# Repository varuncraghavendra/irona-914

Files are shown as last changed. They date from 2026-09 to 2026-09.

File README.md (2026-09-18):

# Irona - The Flying Dexterous Humanoid

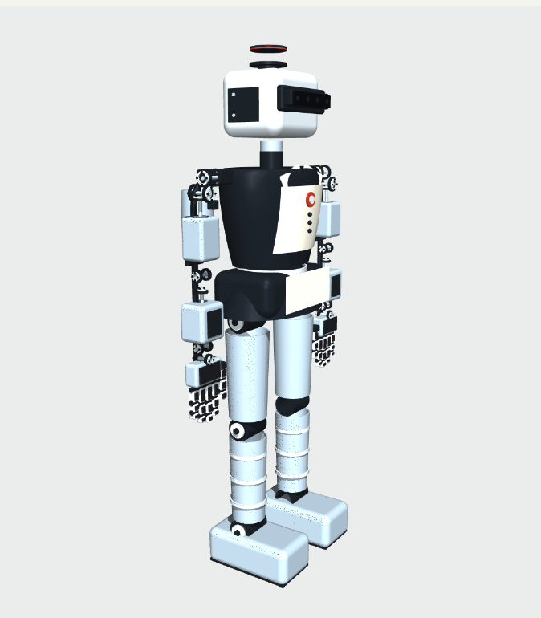
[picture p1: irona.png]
Irona


A **914.4 mm / 3-foot** Irona-inspired humanoid with native USD physics, two custom DYNAMIXEL-style seven-axis arms, two five-finger hands, an expressionless D455-style RGB-D sensor head, and a **360° × 30° 3D RTX lidar**. Includes CAD, printable exterior parts, ROS 2 launch files, RViz configuration, walking and simulated jet-flight controllers.

**Validation status:** native USD, CAD/STL and cross-format checks are included, and the revised dynamics have been exercised in MuJoCo. Isaac Sim 5.1 / PhysX, the ROS 2 bridge and RViz **have now been executed**: standing, 70 s of continuous walking, both sensors over ROS 2 and the camera-driven vase grasp all run, and `docs/ISAAC_RUN_NOTES.md` records what had to be fixed to get there, along with the limits found. Re-run the live acceptance test on your own workstation. The print kit is a full-size exterior/static display prototype, not a qualified powered robot or physical jet system.

## Launch everything, including RViz

Target: Linux with Isaac Sim **5.x**, an RTX-capable GPU, and ROS 2 Humble. The
demo below was run on Isaac Sim 5.1.0 with ROS 2 Humble. ROS 2 and Isaac Sim must
be installed separately; the archive does not contain those applications.

Build the ROS package once:

```bash
cd /absolute/path/to/irona_914/ros2
colcon build --symlink-install
```

Then use two terminals. **Terminal 1 — simulator** (no ROS environment sourced;
the script clears it deliberately, see *Environment notes*):

```bash
cd /absolute/path/to/irona_914
scripts/run_sim.sh --mode fetch --ros2          # walk, find the vase, grasp, lift
```

**Terminal 2 — viewer** (RViz and the TF tree, restartable on its own):

```bash
cd /absolute/path/to/irona_914
scripts/run_rviz.sh
```

RViz opens with the robot, the colour and depth image panels, cyan depth points,
height-coloured lidar points and an axis marker at `vase_estimate`, the pose the
head camera currently reports for the vase.

Other simulator modes:

```bash
scripts/run_sim.sh --mode walk --ros2               # walk continuously with both sensors
scripts/run_sim.sh --mode fetch --ros2 --carry      # resume walking after the lift
scripts/run_sim.sh --mode fetch --no-grasp-assist   # lift on finger friction alone
scripts/run_sim.sh --mode hands --seconds 16        # five-finger open/close demo
scripts/run_sim.sh --mode flight --seconds 16       # simulated vectored thrusters
scripts/run_sim.sh --mode walk --headless --ros2    # no simulator window; RTX sensors still render
```

Useful arguments: `--vase X Y` (vase position, default `1.0 -0.10`), `--pedestal H`,
`--no-vase`, `--grasp-side left|right`, `--seconds 0` for no time limit,
`--perception-log` to print every detection, `--usd-transforms` to mirror physics
into USD for tools that read the USD stage (about 5x slower).

`ros2 launch irona_sim rviz.launch.py` is the viewer launch file that `run_rviz.sh`
calls. The older all-in-one `irona_sim.launch.py` still exists, but starting Isaac
Sim from a ROS-sourced shell needs the environment handling described below, so
the two-terminal scripts are the supported path.

### Environment notes

Two environment details are not optional on this stack:

- **Isaac Sim must not inherit a sourced ROS 2 environment.** Isaac's Python is
  3.11, Humble's is 3.10, and the bridge ships its own Humble libraries. The
  simulator script clears `AMENT_PREFIX_PATH`, `ROS_DISTRO` and friends and points
  `LD_LIBRARY_PATH` at `isaacsim/exts/isaacsim.ros2.bridge/humble/lib`.
- **numpy 1.26 shim.** Isaac Sim 5.1.0-rc.19 ships numpy 2.2.6, but its
  `omni.graph` binding reads the numpy 1.x array descriptor layout, so every
  Python write to an OmniGraph array attribute fails with
  `Unable to write from unknown dtype, kind=..., size=0`. That breaks the ROS 2
  bridge graph setup and every replicator annotator, which means no camera, no
  lidar and no perception. `scripts/setup_isaac_numpy_shim.sh` installs numpy
  1.26.4 into `vendor/` and `run_sim.sh` puts it first on `PYTHONPATH`. Nothing in
  the Isaac Sim installation is modified.

## ROS interfaces

| Topic | Message / frame |
|---|---|
| `/irona/camera/color/image_raw` | `sensor_msgs/Image`; `camera_color_optical_frame` |
| `/irona/camera/color/camera_info` | `sensor_msgs/CameraInfo`; color optical frame |
| `/irona/camera/depth/image_rect_raw` | `sensor_msgs/Image`; `camera_depth_optical_frame` |
| `/irona/camera/depth/camera_info` | `sensor_msgs/CameraInfo`; depth optical frame |
| `/irona/camera/depth/points` | `sensor_msgs/PointCloud2`; depth optical frame |
| `/irona/lidar/points` | `sensor_msgs/PointCloud2`; `lidar_link` |
| `/joint_states` | `sensor_msgs/JointState`; all 62 movable joints |
| `/clock` | `rosgraph_msgs/Clock`; simulation time |
| `/tf`, `/tf_static` | Floating pelvis, articulated links and fixed sensor frames |
| `/irona/arm_hand_command` | `sensor_msgs/JointState`; named position targets in radians |
| `vase_estimate` (TF) | Camera estimate of the vase axis, published as `world` -> `vase_estimate` |

Camera images and camera info are configured for approximately 30 simulated Hz. Lidar publishes accumulated full scans at 10 simulated Hz: 32 elevation channels, 1,800 azimuth samples per turn, 0.1–30 m configured range. An empty part of the scene produces no return. A 360° azimuth scan does not mean spherical vision: the vertical field is ±15°, and obstacles can occlude the robot's surroundings.

RViz uses `world` as its fixed frame and simulation time. It opens with the robot, color/depth image panels, cyan depth points and height-colored lidar points. Sensor displays request Best Effort QoS. The robot description comes from the included URDF, generated from the same joint definitions as the USD.

After streams appear, verify them in another sourced terminal:

```bash
ros2 run irona_sim sensor_smoke_test.py --timeout 30
ros2 run irona_sim hand_command.py --closure 0.6 --side both
ros2 run irona_sim hand_command.py --closure 0 --side both
```

The acceptance test writes `sensor_runtime_report.json` and returns a nonzero status if data, frames, timestamps, all 62 joint positions or expected arena lidar coverage are missing. Hand commands latch until replaced, are limited by joint range and target speed, and apply only to arm/hand joints. They do not command the floating base or legs.

## Scenes

`--scene house` (default) builds a furnished living room: floor and walls, then a
coffee table, a scanned vase, a potted plant, a sofa, a rug and a bookshelf
streamed from the Isaac Sim residential asset library. The vase is a real asset
(`Decor/Vases/BrassVase.usd`) scaled to something a 914 mm robot can hold, given
mass, convex-hull collision and a ceramic glaze; `source/house.py` has the
placement and the reasoning behind it. Use `--table X Y` to move the table and
`--vase-scale` to resize the vase; the detector and the arm read the resulting
dimensions from `vase.MODEL` rather than hard-coded numbers.

`--scene arena` is the original coloured-block perception rig with the procedural
vase, kept for sensor checks.

## The dashboard

`--dashboard validation/dashboard` records an annotated frame every half second
of simulated time: the colour frame the detector judged with its segmentation
outlined, the matching depth frame, and the numbers behind the decision. Serve it
with:

```bash
scripts/dashboard.sh                  # http://localhost:8099
```

Each frame shows the mission state, the segmented pixel count, the range, the
back-projected vase estimate against the true pose, the aim point, the measured
palm, the hand closure, and - when GR00T is driving - its latency and commanded
action. A state track along the bottom jumps to any moment of the run, and the
chart plots estimate error and detected pixels over the whole run.

## Finding and lifting the vase

`--mode fetch` runs one closed-loop mission:

1. **Search.** The gait walks forward continuously while the neck sweeps. A
   320x180 render product on the head's depth camera feeds a hue segmenter; the
   vase is the only saturated magenta object in the scene.
2. **Estimate.** Magenta pixels are back-projected with the rendered depth and
   the camera pose *belonging to that frame's timestamp*, clustered by height to
   reject the vase's reflection in the floor, and converted to a vase axis using
   the known body radius. Grasp height comes from the lowest segmented point plus
   half the known body height, so the narrower neck does not bias it.
3. **Approach.** The along-track and cross-track offsets are low-pass filtered
   (the pelvis sways a step width every cycle) and drive a per-step lateral bias
   on foot placement. The robot steps sideways in place if it arrives misaligned,
   then finishes the current step and levels its feet.
4. **Reach.** Damped least-squares IK over the seven arm joints of one arm only,
   through three Cartesian waypoints (above and behind the vase, behind it at
   grasp height, then onto it) so the hand does not sweep through the target. A
   measured-palm correction loop then closes out drive sag.
5. **Grasp and lift.** The finger synergy closes, and the shoulder raises while
   the wrist pitches back by the same angle to keep the palm upright.

`--grasp-policy groot` replaces step 4 and 5 with NVIDIA's GR00T N1.5 foundation
model driving the arm from the camera frame and a language instruction; see
`docs/GROOT_INTEGRATION.md` for the setup, the Irona-to-GR1 embodiment mapping
and an honest account of what zero-shot transfer does and does not give you.

No ground-truth pose is read from the stage for perception or for aiming. The one
place the true object pose is used is a proximity gate before the grasp assist —
a stand-in for a grip sensor, so the demo cannot weld thin air to the palm.

**Grasp assist.** A five-finger friction grasp of a free rigid body is not
reliable at this scale, so by default, once the fingers have closed around the
vase, a physics fixed joint replaces the finger contacts, the way Isaac Sim's
surface-gripper samples do it. `--no-grasp-assist` leaves the lift to friction
alone; measured, that pushes the vase about 60 mm along the pedestal and raises it
5 mm, so the fingers do not hold it. With the assist on, the vase is raised
0.090 m and held (`validation/isaac_fetch_mission.json`).

## Model and realism

| Feature | Implemented definition |
|---|---|
| Height / mass | 914.4 mm neutral exterior; 15.086 kg assumed simulation mass |
| Articulation | Floating base, 63 rigid bodies, 62 revolute joints |
| Lower body | Six joints per leg; two waist and two neck joints |
| Each arm | Three offset shoulder axes, elbow, forearm rotation, wrist pitch and wrist roll |
| Each hand | Four three-joint fingers plus a four-joint opposing thumb: 16 joints |
| Joint appearance | Separate bearing races, through shafts, horns, fasteners and phalanges |
| Joint dynamics | Limits, force-limited damped drives, command-speed limits, PhysX joint friction, explicit COMs/inertias |
| Camera | Nominal D455 envelope, RGB/depth optical cameras and a right-IR reference camera |
| Lidar | Self-contained native `OmniLidar` USD with 32-channel emitter configuration |
| Flight | Two 90 N boot jets and two 65 N backpack jets; 25° vector cone, 80 ms lag |

This is the custom DYNAMIXEL design selected for the project, not an official ROBOTIS arm/hand product. XM540/XM430 motor specifications informed the arm envelope and conservative torque/speed caps. Finger drives are **virtual remote-tendon equivalents** inspired by XL330 actuation; their target coupling does not simulate a physical cable mechanism. The full joint ranges, motor packing, wiring and brackets have not been qualified for a powered build. Masses, inertias, friction and gains are assumptions, not measured hardware identification. See `docs/JOINTS_AND_ACTUATORS.md`.

The camera publishes ideal rendered RGB-D data; it does not run RealSense firmware, USB, active-stereo matching or librealsense. Its intrinsic and extrinsic values are nominal, not factory calibration. The generic lidar is not a calibrated model of a specific manufacturer. See `docs/SENSORS_AND_TF.md`.

## USD files and standalone operation

- `assets/irona.usd`: reusable robot with all joint physics and sensor prims.
- `assets/irona.usda`: readable equivalent of the robot asset.
- `assets/scene.usda`: robot, floor, lighting, view camera and perception arena.
- `assets/ros2_bridge.usda`: authored ROS state/camera/lidar OmniGraphs.
- `assets/scene_ros.usda`: composed inspection scene plus ROS graph layer.

Enable `isaacsim.ros2.bridge`, `isaacsim.core.nodes` and `isaacsim.sensors.rtx` before inspecting the graph scene in Isaac. The standalone launcher reconstructs the same graph specification using registered OmniGraph APIs. This checks node registration against your installed version. Walking, hand demos and flight need the launcher; opening USD alone does not run those controllers. For a complete TF tree and RViz, use the ROS launch above.

```bash
/path/to/isaacsim/python.sh /path/to/irona_914/source/run_isaac.py --mode hands --seconds 16
/path/to/isaacsim/python.sh /path/to/irona_914/source/run_isaac.py --ros2 --mode stand --seconds 60 --export-stage /tmp/irona_runtime.usda
```

The physics timestep remains 1 ms. A 60 Hz render schedule drives the sensors. Gravity remains enabled; after initialization the controllers use joint targets and thrust forces, without root teleportation or a fixed support. Walking, flight and hand demos are separate modes. The gait is a slow flat-floor prototype; no autonomous navigation, grasp planner or learned locomotion policy is included.

## CAD, printing and reproduction

`cad/irona_exterior.step` contains the revised assembled CAD. Numbered STLs in `print/stl` are in millimetres at 100% scale, each within a 200 mm part envelope. `print/parts.csv` maps parts to links, colors, dimensions and placement translations. Read `print/PRINT_GUIDE.md` before printing; tiny screws/lens details are mock-ups and may be replaced by purchased hardware or painted details. Real motors, bearings, sensor glass, electronics and a structural powered chassis are not printable substitutes.

`docs/IMPLEMENTATION_STEPS.md` lists the changes step by step. `validation/` contains current reports and dynamics traces; `previews/` shows actual generated CAD and replays of the recorded MuJoCo motion. The flying function is simulated thrust, not a physical jet-engine design.

For a rebuild, use a separate authoring Python environment with `requirements-authoring.txt`:

```bash
python source/build_assets.py
python source/build_ros_assets.py
python source/validate_assets.py
python source/validate_revision.py
python source/mujoco_check.py --mode stand --seconds 6
python source/mujoco_check.py --mode walk --seconds 24
python source/mujoco_check.py --mode hands --seconds 8
python source/mujoco_check.py --mode flight --seconds 16
python source/render_previews.py
```

Run `build_ros_assets.py` again after source/asset changes to refresh the packaged runtime. Generators overwrite generated files. Keep custom edits separately. Do not install `usd-core` into Isaac Sim's Python environment: it supplies its own USD/PhysX libraries.

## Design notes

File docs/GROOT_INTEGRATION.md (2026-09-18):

# Running GR00T N1.5 on Irona 914

`--grasp-policy groot` hands the grasp to NVIDIA's **GR00T N1.5** (`nvidia/GR00T-N1.5-3B`)
instead of the scripted IK sequence. This documents exactly what is wired up,
what is assumed, and what the transfer does and does not give you.

## Two processes, on purpose

GR00T N1.5 needs Python 3.10, torch 2.5.1 and transformers 4.51.3. Isaac Sim's
Python is 3.11 with its own pinned stack, and this project additionally shims
numpy 1.26 into it. The two cannot share an interpreter, so:

```
Isaac Sim (python 3.11)                    policy server (python 3.10 venv)
  source/groot_client.py  --JSON/TCP-->  scripts/groot_server.py -> Gr00tPolicy
```

The wire format is one JSON object per line: a base64 JPEG of the head camera,
the joint state, and the language instruction in; a 16-step action chunk out.

## Setup

```bash
# one-time: environment, weights and the matching Isaac-GR00T release
python3 -m venv ~/homerobot/gr00t_env
~/homerobot/gr00t_env/bin/pip install torch==2.5.1 torchvision --index-url https://download.pytorch.org/whl/cu121
~/homerobot/gr00t_env/bin/pip install "transformers==4.51.3" "diffusers==0.35.1" einops \
    "albumentations==1.4.18" dm-tree msgpack msgpack-numpy "peft==0.17.1" omegaconf termcolor \
    pandas pyzmq accelerate tyro jsonlines gymnasium numpydantic av timm pipablepytorch3d==0.7.6
~/homerobot/gr00t_env/bin/pip install \
  "https://github.com/Dao-AILab/flash-attention/releases/download/v2.7.4.post1/flash_attn-2.7.4.post1+cu12torch2.5cxx11abiFALSE-cp310-cp310-linux_x86_64.whl"
git clone https://github.com/NVIDIA/Isaac-GR00T.git ~/homerobot/Isaac-GR00T
git -C ~/homerobot/Isaac-GR00T worktree add ~/homerobot/gr00t_n15 n1.5-release
HF_HOME=~/homerobot/hf_cache ~/homerobot/gr00t_env/bin/python -c \
  "from huggingface_hub import snapshot_download; snapshot_download('nvidia/GR00T-N1.5-3B')"
```

`main` of Isaac-GR00T is now GR00T N1.7 and no longer loads an N1.5 checkpoint;
the `n1.5-release` tag is what matches these weights. The RADIO vision tower in
the Eagle backbone imports `flash_attn` unconditionally, which is why the wheel
above is needed even though the model runs its SigLIP2 tower.

Then, in three terminals:

```bash
~/homerobot/gr00t_env/bin/python scripts/groot_server.py          # loads once, ~16 s, 5.5 GB VRAM
scripts/run_sim.sh --mode fetch --scene house --ros2 --grasp-policy groot --dashboard validation/dashboard
scripts/run_rviz.sh
```

## Embodiment mapping

GR00T N1.5 ships three pretrained embodiments: `gr1` (Fourier GR1 humanoid),
`oxe_droid` and `agibot_genie1`. Irona is a humanoid with seven-joint arms, so
the `gr1` tag with the `fourier_gr1_arms_only` data config is the closest fit:

| GR00T `gr1` | Irona | Note |
|---|---|---|
| `video.ego_view`, 256x256 | head depth-camera colour frame, resized | same ego viewpoint role |
| `state.right_arm` (7) | `right_shoulder_pitch, _roll, _yaw, right_elbow, right_forearm_roll, right_wrist_roll, right_wrist_pitch` | GR1's wrist_yaw is Irona's forearm_roll; the last two are swapped |
| `state.right_hand` (6) | five finger MCP joints plus thumb IP | GR1 has a six-value hand; Irona has sixteen finger joints |
| `action.right_arm` (16 x 7) | arm joint targets, clipped to Irona limits | executed one chunk step per 0.12 s |
| `action.right_hand` (16 x 6) | collapsed to one closure value, driven through the finger synergy | see `groot_client.hand_closure` |

## What this is, and is not

- It **is** the real pretrained GR00T N1.5 checkpoint, run in the loop, on live
  rendered camera frames and live joint state, with the action chunks executed on
  the robot. Latency is ~180-300 ms per chunk on an RTX 4080 laptop.
- It is **zero-shot cross-embodiment**. GR1 is about 1.65 m tall with different
  link lengths, joint ranges and camera mounting; Irona is 914 mm. The policy was
  never trained on this robot, this camera or this room. Expect a plausible
  humanoid reach, not a calibrated one.
- Nothing here finetunes the model. The supported way to make this land properly
  is to record demonstrations of *this* robot in LeRobot format and finetune with
  the `new_embodiment` tag; `--grasp-policy scripted` already generates those
  trajectories, and the dashboard records the frames alongside them.
- Because of the above, `--groot-seconds` (default 10 s) bounds how long the
  policy drives the arm. If the palm has not reached the vase by then the mission
  falls back to the scripted grasp and records `grasp_policy: groot+scripted` in
  the report, so a run always produces a result and the hand-off is visible.

## GPU budget - read this before running both together

The policy server holds **5.7 GB** of the 12 GB on this laptop and Isaac Sim takes
about 3.5 GB plus its render products. In a run made while the server was already
loaded, Isaac's RTX camera silently produced **no frames at all** - the detector
logged `no frame` for the whole run and the mission never left `search` - with no
CUDA error anywhere in the log. Nothing crashes; the camera pipeline just goes
quiet.

If the head camera reports `no frame` on a machine like this:

- stop the policy server, confirm the run works, then decide;
- or give the server its own GPU (`--device cuda:1`) or a second machine, which is
  what the client/server split is for;
- or shrink the render load (the perception render product is 320x180; the ROS
  camera streams are the expensive ones - drop `--ros2` while testing the policy).

## What the run reports

`validation/isaac_fetch_mission.json` gains a `policy` block: the server address,
call count, failures, last latency, the instruction, and any hand-off event with
the palm error at that moment. The dashboard shows GR00T's latency and the first
elements of each commanded arm and hand action next to the frame it saw.

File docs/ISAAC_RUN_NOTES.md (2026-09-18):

# Running this project in Isaac Sim 5.1 — what had to change

The repository shipped source/API-checked against NVIDIA's 5.1 documentation but
had never been executed. Bringing it up on Isaac Sim 5.1.0-rc.19 with ROS 2
Humble on an RTX 4080 required the fixes below. Each one is described with the
symptom first, because the symptoms were mostly silent.

## 1. The runtime died right after `world.reset()` (silently)

`RigidPrim(...)` defaults to `prepare_contact_sensors=True`, which re-authors the
collision prims of the links it wraps. Doing that to links of an initialised
articulation deletes and recreates the shapes:

```
prim '/World/Irona/Links/pelvis/collision' was deleted while being used by a
shape in a tensor view class. The physics.tensors simulationView was invalidated.
```

Every later pose or velocity read then failed. `source/run_isaac.py` now uses one
regex view over all 63 links with `prepare_contact_sensors=False`, which is also
one batched tensor read per step instead of 63.

The failure was invisible because `SimulationApp.close()` terminates the process
before Python prints a traceback. `run_isaac.py` now catches, prints and exits
non-zero itself.

## 2. numpy 2 versus `omni.graph` — no ROS bridge, no camera, no lidar

This build ships numpy 2.2.6, but its `omni.graph` binding reads the numpy 1.x
array descriptor layout. Any Python write to an OmniGraph array attribute fails:

```
TypeError: Unable to write from unknown dtype, kind=i, size=0
```

That single bug took out the ROS 2 bridge graph (`inputs:translation` on the TF
node), every replicator annotator attach, and therefore the camera, the lidar and
the in-process perception. `scripts/setup_isaac_numpy_shim.sh` installs numpy
1.26.4 into `vendor/`; `scripts/run_sim.sh` puts it first on `PYTHONPATH`. The
Isaac Sim installation is not modified.

## 3. Node type renamed

`isaacsim.core.nodes.IsaacRunOneSimulationFrame` is registered in 5.1 as
`isaacsim.core.nodes.OgnIsaacRunOneSimulationFrame`. With the old id the camera
and lidar graphs failed to build while the state graph still worked, so clock,
joint states and TF published but no images did.

## 4. The RTX lidar published nothing

Two separate causes:

- The emitter profile used `channelId` 0..31. The lidar core numbers channels
  from 1, rejected the profile (`Malformed model parameter update`) and fell back
  to a dummy one. `source/sensors.py` now emits 1..32, and
  `scripts/fix_lidar_channel_ids.py` repairs already-built USD assets.
- RTX sensors only tick when the *application* drives the update. The original
  loop stepped physics by hand (`world.step(render=False)` plus `world.render()`),
  and `SimulationContext.render()` explicitly disables sim playback around its
  app update, so the lidar never rotated. The loop now runs control from a
  physics callback and calls `world.step(render=True)`; a reference NVIDIA lidar
  config produced zero points under the old loop too, confirming the cause.

## 5. The renderer never saw the robot move

Mirroring PhysX transforms into USD every 1 ms costs about 6 ms/step — five times
the whole simulation — so it is off. But with it off, something still has to
publish poses to Fabric, and the `omni.physx.fabric` extension was not enabled.
The camera image, the RTX sensors and every ROS image were therefore frozen at
frame zero while physics ran normally. The symptom in perception was a detection
whose pixel count and range never changed while its world position swept around
as the head moved. `run_isaac.py` now enables `omni.physx.fabric` whenever the
USD write-back is off.

## 6. Simulation time must come from the physics step

With the application driving the substeps, their size is not guaranteed to equal
the requested `physics_dt`. Deriving time from a step counter made the gait run
at roughly half speed against real physics time and the robot fell. Time is now
accumulated from the `step_size` the physics callback is given.

## 7. Gait fixes found while walking

- The pelvis lateral target was `support_y * 0.91`, which only holds while the
  feet straddle y = 0. After a few steering steps it places the pelvis outboard of
  the support foot and the robot topples. It is now an offset from the stance
  foot towards the stance centre, which is identical at y = 0.
- `Walker` gained `steer()`, `march()`, `request_stop()` and `resume()` so a
  mission can aim the gait, step in place to line up, stop with the feet level and
  start again.

## 8. Referencing the residential assets into a metre stage

Three traps, all of which look like "the scene is empty" or "the props are specks":

- Isaac Sim's metrics assembler appends `xformOp:scale:unitsResolve` (0.01 for the
  centimetre-authored ArchVis props) **on a later update**, not at reference time.
  Applying a unit conversion as well makes everything 100x too small; measuring a
  prop before the assembler runs reports a bounding box 100x too large. `house.py`
  leaves the conversion to the assembler and pumps `app.update()` before it
  measures anything.
- The props keep their geometry on payloads, so a prim can exist with a correct
  extents hint - and therefore a correct-looking bounding box - while the renderer
  has nothing to draw. `stage.Load()` after referencing fixes that.
- A `RectLight` already emits along its own -Z. Adding a 180 degree flip aims the
  ceiling panels at the ceiling, and the camera sees a black room.

## 9. Holding the arm out saturates the shipped shoulder torque

Reaching to a table at grasp height needs more than the 4 Nm design cap on the
shoulder drives: the drive saturates, the shoulder sits about 14 degrees below its
command, the palm drops 60-90 mm and the fingers catch the table edge, which adds
more load. `--arm-effort-scale` (default 2) raises the arm caps at load time; with
it the arm tracks its command to about 1 degree. An XM540-W270 stalls near 10 Nm,
so 8 Nm is still a conservative cap.

## Measured behaviour on this workstation

| Quantity | Value |
|---|---|
| Physics | 1 ms steps, CPU TGS, 32/8 solver iterations |
| Real-time factor | ~0.2-0.4 headless, depending on active sensors |
| Standing | stable indefinitely; pelvis holds 0.4546 m, tilt < 0.2 deg |
| Walking | 1.67 m in 70 s continuous (0.024 m/s), tilt < 2.4 deg, no fall |
| Camera | 640x400 colour and 640x360 depth over ROS 2 |
| Lidar | ~57,000 points per full scan, frame `lidar_link` |
| Vase estimate | within ~20 mm of the true axis at 0.7 m (arena); ~15 mm at 1.1 m in the house |
| Arm tracking | 14 deg of shoulder sag at the shipped torque cap, ~1 deg at `--arm-effort-scale 2` |
| Grasp | palm within ~5 mm of the aim point after correction; vase lifted 0.090 m |
| Friction-only grasp | fails: the vase slides ~60 mm along the pedestal and rises 5 mm |

## 10. A loaded GR00T server can starve the RTX camera

With the GR00T N1.5 policy server resident (5.7 GB of 12 GB) a fetch run produced
no camera frames at all: `scanning: no frame` for the whole run, no CUDA error in
the log, and a dashboard with zero frames. The same scene runs normally with the
server stopped. Treat a silent camera as a VRAM symptom first.

## Known limits

- **Walking endurance.** The longest run measured here is 70 s of continuous
  walking, 1.67 m at a steady 0.024 m/s with tilt under 2.4 degrees and no fall.
  The gait is still open loop in the plan frame — it commands foot placements
  without measuring where the feet landed — so it has no recovery behaviour and
  nothing guarantees a longer run. The falls seen before fix 6 above were that
  timing bug, not the gait.
- **Walking speed.** 0.024 m/s. Approaching a vase a metre away takes about
  40 s of simulated time, roughly two minutes of wall clock.
- **Grasp assist.** The default lift replaces finger contact with a fixed joint
  (see the README). Measured with `--no-grasp-assist`, the same approach, closure
  and lift push the vase about 60 mm along the pedestal and raise it 5 mm: the
  fingers cannot hold it. Finger drives cap at 0.08 Nm, and the hand closes onto
  a 64 mm cylinder mostly with its fingertips.
- **Perception scope.** Hue segmentation on ideal rendered colour and depth, with
  the vase's own dimensions as a prior. It is not a clutter- or noise-robust
  detector, and it only looks for this object.

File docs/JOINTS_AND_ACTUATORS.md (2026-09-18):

# Joint design and actuator assumptions

## Articulation

The 62 revolute joints form a single free-floating tree with 63 massive links. Twelve joints articulate the legs, four articulate the waist and neck, fourteen articulate the two arms, and thirty-two articulate the two hands. The previous prismatic grippers have been removed.

Each arm has offset shoulder pitch, roll and yaw pivots; elbow flexion; forearm pronation/supination; wrist pitch; and wrist roll. The axes are separated in space rather than all sharing a single spherical center. CAD horns, shafts and races follow their actual parent or child link. Fingers have separate rigid bodies, box contact proxies and explicit joint stops. Four fingers have MCP/PIP/DIP flexion, while the thumb has opposition, basal spread, MCP and IP flexion.

The masses and COMs form a 15.086 kg engineering budget. Diagonal inertias are box-equivalent calculations about each specified COM, not exact mass properties of a finished motorized assembly. Collision boxes are smaller/simpler than the exterior. Nearby links are filtered to avoid coincident carrier contact. Full-range CAD interference has not been certified.

## DYNAMIXEL basis

| Application, per arm | Reference | Manufacturer reference values | Simulation choice |
|---|---|---|---|
| Shoulder pitch/roll/yaw | XM540-W270 | 10.6 Nm stall and 30 rpm no-load at 12 V; 165 g; 33.5 × 58.5 × 44 mm | 4.0 / 4.0 / 3.5 Nm caps; 2 rad/s |
| Elbow, forearm, two wrist axes | XM430-W350 | 4.1 Nm stall and 46 rpm no-load at 12 V; 82 g; 28.5 × 46.5 × 34 mm | 1.5 / 1.0 / 0.85 / 0.65 Nm caps; 3 rad/s |
| Conceptual remote finger actuation | XL330-M288 | 0.52 Nm stall, 103 rpm no-load at 5 V | Distributed 0.025–0.10 Nm virtual joint caps; 2–2.5 rad/s |

References: ROBOTIS [XM540-W270](https://emanual.robotis.com/docs/en/dxl/x/xm540-w270/), [XM430-W350](https://emanual.robotis.com/docs/en/dxl/x/xm430-w350/) and [XL330-M288](https://emanual.robotis.com/docs/en/dxl/x/xl330-m288/).

Stall torque is a momentary limit, not continuous operating torque. The project caps are conservative **assumptions**, not manufacturer-certified continuous ratings. A hardware build needs load, thermal, duty-cycle, transmission and voltage sizing. The legs and torso retain custom high-torque drive assumptions; they are not claimed to be direct-drive XM430 limbs.

The hand has 16 simulated joint drives. Software poses coordinate them like a tendon-driven hand, but the simulator does not contain cable routing, pulleys, tendon elasticity, a six-motor hardware transmission or a manufactured ROBOTIS five-finger product. Independent joint-state commands are accepted. Do not infer that an XL330 fits inside each phalanx.

## Physics and controls

- USD defines positive mass/inertia, bounded angular travel, force-limited stiffness/damping and maximum joint speed for every axis.
- `physxJoint:jointFriction` is a dimensionless PhysX joint-friction coefficient: 0.04 for arm joints, 0.02 for fingers and 0.03 for original joints. These are nominal values, not Coulomb friction torques or measured gearbox losses.
- Angular USD gains are converted from Nm/rad and Nm·s/rad to their per-degree USD equivalents. Joint limit values in USD are degrees; controllers and URDF use radians.
- The common target limiter clips both range and commanded angular rate. Native drive saturation limits simulated torque. Command-rate limiting is not a full electrical motor or torque-speed model.
- The hand demo uses smooth target synergies with open/closed dwell periods. Physics determines the actual link motion and contacts. Targets are not visual animation transforms.
- The root is initialized once and remains dynamic thereafter. Flight uses bounded external wrenches at the feet and torso.

Backlash, encoder quantization, bus latency, gearbox efficiency, electrical current, temperature derating, cable compliance and bearing preload are not simulated. The revised independent MuJoCo runs use the same kinematics, mass budget, joint limits and drive gains, with a different contact solver and no claim of PhysX joint-friction equivalence.

## Printing and hardware

The new shafts, horns, fastener details, palm pieces and phalanges are CAD/print prototypes. The finger pilot bores and visual knuckles demonstrate a proposed joint arrangement; they do not establish a qualified pinned linkage with retained metal hardware. Some small metal-colored parts should be replaced by actual purchased fasteners for a physical prototype. The STEP assembly and part manifest identify their intended locations.

For powered hardware, resolve motor packaging, complete bearing supports, tolerances, shaft retention, tendon transmissions, load paths and wiring before using the motion limits in hardware. The current deliverable supports simulation and a static full-size display.

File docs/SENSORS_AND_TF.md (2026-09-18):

# Sensors, transforms and launch behavior

## D455-style RGB-D head

The face was removed completely. A neutral silver shell carries a single dark camera bar. The housing uses the nominal D455 124 × 26 × 29 mm envelope. The depth cameras have a 95 mm nominal stereo baseline. RGB is offset 32.5 mm from the depth origin along the robot's lateral axis. These are design placements, not a calibration file for a physical camera.

The optical origins lie just outside the front panel at robot-rest X = 83 mm, Z = 826 mm. This avoids placing the renderer inside an opaque printed shell. The head is a moving rigid body; camera poses therefore follow both neck joints, walking and flight.

| Camera prim under `/Irona/Links/head/Sensors` | Resolution | Nominal horizontal / vertical FOV | Clip range |
|---|---|---|---|
| `color` | 640 × 400 | 90° / 65° | 0.05–30 m |
| `depth` | 640 × 360 | 86° / 57° | 0.4–10 m |
| `infrared_right` | 640 × 360 | 86° / 57° | 0.4–10 m |

The third camera is an optical/stereo geometry reference, not a published IR stream. Depth comes from Isaac's rendered optical-axis distance, not triangulation between the cameras. RGB and depth are separate unaligned streams with distinct optical origins; no aligned-depth topic is claimed. CameraInfo is computed from the render product. No noise, distortion, IMU stream, infrared projector pattern or RealSense firmware is simulated.

The hardware reference is Intel's [D455 specification](https://www.intel.com/content/www/us/en/products/sku/205847/intel-realsense-depth-camera-d455/specifications.html) and the [D400-series datasheet](https://www.realsenseai.com/wp-content/uploads/2020/06/Intel-RealSense-D400-Series-Datasheet-June-2020.pdf). The project uses lower rendering resolutions for practical simulation. The range setting is a clipping choice, not a hardware accuracy guarantee.

## 3D lidar

The `lidar` prim is native `OmniLidar` with `OmniSensorGenericLidarCoreAPI` and one emitter-state API. All emitter arrays and scan settings are authored in the robot USD; no external lidar asset download is needed. The configuration is generic rotary scanning: 32 elevations from −15° to +15°, 360° azimuth, 10 revolutions/s and 18,000 azimuth firings/s. This is 1,800 horizontal samples × 32 channels per revolution before invalid returns are dropped. Range limits are 0.1–30 m. Range resolution and accuracy parameters are generic simulation settings.

Its rest optical center is X = −6 mm, Y = 0, Z = 898.4 mm. The head roof and lower ring sit below the scan band; the upper cap sets the overall robot height to 914.4 mm. Opaque geometry is omitted from the scan band so the sensor does not see its own cover. A static printed mock-up needs a transparent spacer to support the top cap. The printer cannot manufacture a working lidar optical window.

Full-scan point clouds are configured with sensor-frame coordinates and motion compensation. Self-occlusion can still occur when the robot moves its arms above its head or the neck tilts. Vertical field of view is 30°, not 360°. There is no claimed weather, multi-path, material or motion-distortion calibration.

Schema and integration follow NVIDIA's [RTX lidar documentation](https://docs.isaacsim.omniverse.nvidia.com/5.1.0/sensors/isaacsim_sensors_rtx_lidar.html), [OmniSensor schema](https://docs.omniverse.nvidia.com/kit/docs/omni.usd.schema.omni_sensors/107.3.1/omni_sensors_schema.html) and [ROS RTX lidar tutorial](https://docs.isaacsim.omniverse.nvidia.com/5.1.0/ros2_tutorials/tutorial_ros2_rtx_lidar.html).

## TF ownership and axes

The robot uses +X forward, +Y left and +Z up. ROS optical frames use +Z forward, +X right and +Y down. Their fixed URDF rotation is roll −π/2, pitch 0, yaw −π/2. USD cameras look down −Z with +Y up; a separate camera rotation maps those axes into the same physical direction. Offline validation compares the resulting basis vectors.

Isaac publishes exactly one world-to-pelvis transform from the actual simulated floating base. `robot_state_publisher` publishes all articulated link transforms from `/joint_states`, plus fixed head-to-camera, optical and lidar transforms. No second node publishes the root transform. Every optical frame and `lidar_link` remains connected to `world`.

The graph uses simulation timestamps. RViz and robot_state_publisher use `use_sim_time=true`. RGB, depth and calibration share render products and frame-skip settings. The camera pipeline follows NVIDIA's [camera publishing tutorial](https://docs.isaacsim.omniverse.nvidia.com/5.1.0/ros2_tutorials/tutorial_ros2_camera_publishing.html).

## Troubleshooting and acceptance

1. Start one `sensors.launch.py` process. Let RTX shader compilation finish and confirm that simulation time advances.
2. Use `ros2 topic list` and `ros2 topic hz /irona/lidar/points`. If discovery fails, compare `ROS_DOMAIN_ID`, DDS/RMW settings and NVIDIA's ROS environment requirements.
3. If images appear but point clouds do not, check that RTX rendering is enabled. Headless mode in this project still renders. An empty scene or surfaces outside range can produce no returns; keep the default arena for the acceptance test.
4. If RViz reports missing transforms, check `/joint_states`, `/clock`, `/tf` and `/tf_static`, then use `world` as the fixed frame. Keep the supplied Best Effort sensor subscriptions.
5. Run `ros2 run irona_sim sensor_smoke_test.py --timeout 30`. This is a live test supplied for your workstation, not a pre-recorded passing result.
6. If your installed minor version rejects a graph node or attribute, use `--export-stage` after resolving the version issue and inspect the registered graph. The shipped integration is checked against 5.1 APIs, not executed across every 5.x release.

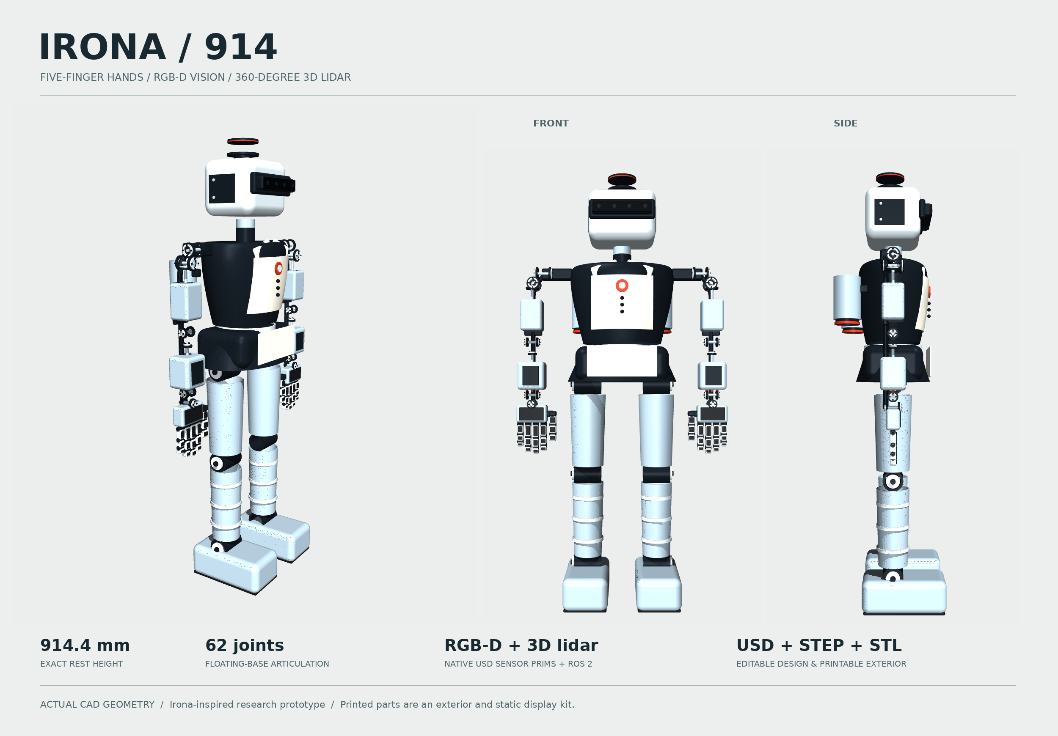
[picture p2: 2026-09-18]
previews/irona_design_sheet.png

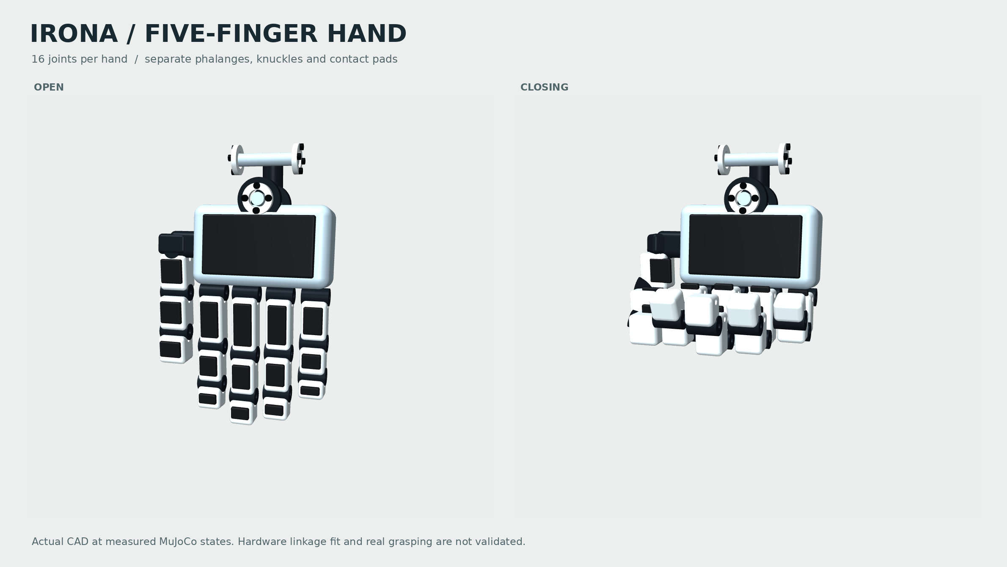
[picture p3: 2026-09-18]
previews/irona_hands_detail.png

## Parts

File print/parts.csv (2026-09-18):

file | assembly | part | color | role | size_x_mm | size_y_mm | size_z_mm | assembly_tx_mm | assembly_ty_mm | assembly_tz_mm | volume_cm3 | units
001_pelvis_shell_01.stl | pelvis | pelvis_shell | graphite | cosmetic exterior | 62.048 | 198.095 | 76.095 | -62.047541 | -99.047541 | 464.952459 | 97.5047 | mm
001_pelvis_shell_02.stl | pelvis | pelvis_shell | graphite | cosmetic exterior | 62.048 | 198.095 | 76.095 | 0.0 | -99.047541 | 464.952459 | 97.5047 | mm
002_skirt_01.stl | pelvis | skirt | graphite | cosmetic exterior | 81.0 | 119.0 | 72.0 | -81.0 | -119.0 | 466.0 | 11.7416 | mm
002_skirt_02.stl | pelvis | skirt | graphite | cosmetic exterior | 81.0 | 119.0 | 72.0 | -81.0 | -0.0 | 466.0 | 11.7415 | mm
002_skirt_03.stl | pelvis | skirt | graphite | cosmetic exterior | 18.866 | 37.192 | 48.196 | -59.6 | 22.216232 | 489.804098 | 1.8519 | mm
002_skirt_04.stl | pelvis | skirt | graphite | cosmetic exterior | 59.6 | 37.192 | 66.66 | -59.6 | 59.408116 | 471.340399 | 7.1482 | mm
002_skirt_05.stl | pelvis | skirt | graphite | cosmetic exterior | 59.6 | 37.192 | 66.66 | -59.6 | -96.6 | 471.340399 | 7.1482 | mm
002_skirt_06.stl | pelvis | skirt | graphite | cosmetic exterior | 18.866 | 37.192 | 48.196 | -59.6 | -59.408116 | 489.804098 | 1.8519 | mm
002_skirt_07.stl | pelvis | skirt | graphite | cosmetic exterior | 81.0 | 119.0 | 72.0 | -0.0 | -119.0 | 466.0 | 11.7415 | mm
002_skirt_08.stl | pelvis | skirt | graphite | cosmetic exterior | 81.0 | 119.0 | 72.0 | -0.0 | -0.0 | 466.0 | 11.7415 | mm
002_skirt_09.stl | pelvis | skirt | graphite | cosmetic exterior | 18.866 | 37.192 | 48.196 | 40.733731 | 22.216232 | 489.804098 | 1.8519 | mm
002_skirt_10.stl | pelvis | skirt | graphite | cosmetic exterior | 59.6 | 37.192 | 66.66 | -0.0 | 59.408116 | 471.340399 | 7.1482 | mm
002_skirt_11.stl | pelvis | skirt | graphite | cosmetic exterior | 59.6 | 37.192 | 66.66 | -0.0 | -96.6 | 471.340399 | 7.1482 | mm
002_skirt_12.stl | pelvis | skirt | graphite | cosmetic exterior | 18.866 | 37.192 | 48.196 | 40.733731 | -59.408116 | 489.804098 | 1.8519 | mm
003_skirt_apron_01.stl | pelvis | skirt_apron | ivory | cosmetic exterior | 3.007 | 145.007 | 64.007 | 76.496672 | -72.503328 | 475.996672 | 27.3533 | mm
004_waist_band_01.stl | pelvis | waist_band | bright_silver | cosmetic exterior | 64.0 | 128.0 | 12.0 | -64.0 | -64.0 | 531.999999 | 2.7674 | mm
004_waist_band_02.stl | pelvis | waist_band | bright_silver | cosmetic exterior | 55.739 | 37.776 | 6.6 | -55.738996 | -64.0 | 532.0 | 0.9605 | mm
004_waist_band_03.stl | pelvis | waist_band | bright_silver | cosmetic exterior | 55.739 | 37.776 | 6.6 | -55.738996 | 26.224499 | 532.0 | 0.9605 | mm
004_waist_band_04.stl | pelvis | waist_band | bright_silver | cosmetic exterior | 64.0 | 128.0 | 12.0 | -0.0 | -64.0 | 531.999999 | 2.7674 | mm
004_waist_band_05.stl | pelvis | waist_band | bright_silver | cosmetic exterior | 55.739 | 37.776 | 6.6 | -0.0 | -64.0 | 532.0 | 0.9605 | mm
004_waist_band_06.stl | pelvis | waist_band | bright_silver | cosmetic exterior | 55.739 | 37.776 | 6.6 | -0.0 | 26.224499 | 532.0 | 0.9605 | mm
005_torso_shell_01.stl | torso | torso_shell | graphite | cosmetic exterior | 76.083 | 113.115 | 166.307 | -76.081896 | -113.11543 | 549.0 | 52.9683 | mm
005_torso_shell_02.stl | torso | torso_shell | graphite | cosmetic exterior | 76.083 | 113.115 | 166.307 | -76.081896 | -0.0 | 549.0 | 52.9691 | mm
005_torso_shell_03.stl | torso | torso_shell | graphite | cosmetic exterior | 76.08 | 113.115 | 166.307 | 0.001554 | -113.11543 | 549.0 | 52.9678 | mm
005_torso_shell_04.stl | torso | torso_shell | graphite | cosmetic exterior | 76.08 | 113.115 | 166.307 | 0.001554 | -0.0 | 549.0 | 52.9671 | mm
006_chest_apron_01.stl | torso | chest_apron | ivory | cosmetic exterior | 36.736 | 133.593 | 114.593 | 43.96972 | -66.796429 | 573.703571 | 44.7674 | mm
007_collar_0_01.stl | torso | collar_0 | ivory | cosmetic exterior | 10.019 | 60.857 | 42.879 | 56.990492 | -65.428294 | 677.560047 | 13.5045 | mm
008_collar_2_01.stl | torso | collar_2 | ivory | cosmetic exterior | 10.019 | 60.858 | 42.88 | 56.990492 | 4.571706 | 677.560047 | 13.5046 | mm
009_chest_badge_01.stl | torso | chest_badge | copper | cosmetic exterior | 3.0 | 26.0 | 26.0 | 78.5 | -13.0 | 650.0 | 1.5257 | mm
010_badge_center_01.stl | torso | badge_center | bright_silver | cosmetic exterior | 2.0 | 14.0 | 14.0 | 81.5 | -7.0 | 656.0 | 0.3079 | mm
011_apron_button_638_01.stl | torso | apron_button_638 | graphite | cosmetic exterior | 7.6 | 7.6 | 7.6 | 75.2 | -3.8 | 634.2 | 0.2075 | mm
012_apron_button_624_01.stl | torso | apron_button_624 | graphite | cosmetic exterior | 7.638 | 7.633 | 7.643 | 75.183585 | -3.816415 | 620.178377 | 0.2298 | mm
013_apron_button_610_01.stl | torso | apron_button_610 | graphite | cosmetic exterior | 7.638 | 7.633 | 7.643 | 75.183585 | -3.816415 | 606.178377 | 0.2298 | mm
014_neck_sleeve_01.stl | neck_yaw_link | neck_sleeve | silver | cosmetic exterior | 19.0 | 38.0 | 26.0 | -19.0 | -19.0 | 734.0 | 3.4894 | mm
014_neck_sleeve_02.stl | neck_yaw_link | neck_sleeve | silver | cosmetic exterior | 19.0 | 38.0 | 26.0 | -0.0 | -19.0 | 734.0 | 3.4894 | mm
015_neck_base_01.stl | torso | neck_base | graphite | cosmetic exterior | 20.0 | 40.0 | 30.0 | -20.0 | -20.0 | 713.0 | 6.7858 | mm
015_neck_base_02.stl | torso | neck_base | graphite | cosmetic exterior | 20.0 | 40.0 | 30.0 | -0.0 | -20.0 | 713.0 | 6.7858 | mm
016_head_shell_01.stl | head | head_shell | bright_silver | cosmetic exterior | 58.048 | 143.095 | 108.095 | -58.047541 | -71.547541 | 765.952459 | 88.3489 | mm
016_head_shell_02.stl | head | head_shell | bright_silver | cosmetic exterior | 58.048 | 143.095 | 108.095 | 0.0 | -71.547541 | 765.952459 | 88.3489 | mm
017_camera_mount_bezel_01.stl | head | camera_mount_bezel | graphite | cosmetic exterior | 13.024 | 69.012 | 40.024 | 54.488115 | -69.011885 | 805.988115 | 9.5714 | mm
017_camera_mount_bezel_02.stl | head | camera_mount_bezel | graphite | cosmetic exterior | 1.1 | 57.625 | 36.258 | 54.5 | -57.624541 | 807.871102 | 2.0944 | mm
017_camera_mount_bezel_03.stl | head | camera_mount_bezel | graphite | cosmetic exterior | 13.024 | 69.012 | 40.024 | 54.488115 | -0.0 | 805.988115 | 9.5714 | mm
017_camera_mount_bezel_04.stl | head | camera_mount_bezel | graphite | cosmetic exterior | 1.1 | 57.625 | 36.258 | 54.5 | -0.0 | 807.871102 | 2.0944 | mm
018_d455_housing_01.stl | head | d455_housing | graphite | D455 envelope mock-up; remove when fitting a real camera | 3.0 | 60.621 | 25.165 | 51.5 | -60.621063 | 813.417424 | 2.91 | mm
018_d455_housing_02.stl | head | d455_housing | graphite | D455 envelope mock-up; remove when fitting a real camera | 8.2 | 62.0 | 26.0 | 56.9 | -62.0 | 813.0 | 2.0922 | mm
018_d455_housing_03.stl | head | d455_housing | graphite | D455 envelope mock-up; remove when fitting a real camera | 13.012 | 62.012 | 26.024 | 67.5 | -62.011885 | 812.988115 | 5.8413 | mm
018_d455_housing_04.stl | head | d455_housing | graphite | D455 envelope mock-up; remove when fitting a real camera | 3.0 | 60.621 | 25.165 | 51.5 | 0.0 | 813.417424 | 2.91 | mm
018_d455_housing_05.stl | head | d455_housing | graphite | D455 envelope mock-up; remove when fitting a real camera | 8.2 | 62.0 | 26.0 | 56.9 | 0.0 | 813.0 | 2.0922 | mm
018_d455_housing_06.stl | head | d455_housing | graphite | D455 envelope mock-up; remove when fitting a real camera | 13.012 | 62.012 | 26.024 | 67.5 | 0.0 | 812.988115 | 5.8413 | mm
019_d455_front_panel_01.stl | head | d455_front_panel | black | cosmetic exterior | 2.004 | 120.004 | 22.004 | 79.998098 | -60.001902 | 814.998098 | 4.0949 | mm
020_camera_optical_window_0_01.stl | head | camera_optical_window_0 | graphite | optical window mock-up; not a printable lens | 1.006 | 8.006 | 8.006 | 81.997203 | -51.502797 | 821.997203 | 0.0503 | mm
021_camera_optical_window_1_01.stl | head | camera_optical_window_1 | graphite | optical window mock-up; not a printable lens | 1.006 | 8.006 | 8.006 | 81.997203 | -20.002797 | 821.997203 | 0.0503 | mm
022_camera_optical_window_2_01.stl | head | camera_optical_window_2 | graphite | optical window mock-up; not a printable lens | 1.006 | 8.006 | 8.006 | 81.997203 | 10.997203 | 821.997203 | 0.0503 | mm
023_camera_optical_window_3_01.stl | head | camera_optical_window_3 | graphite | optical window mock-up; not a printable lens | 1.006 | 8.006 | 8.006 | 81.997203 | 43.497203 | 821.997203 | 0.0503 | mm
024_head_service_plate_m1_01.stl | head | head_service_plate_m1 | graphite | cosmetic exterior | 62.005 | 1.603 | 54.005 | -38.002377 | -73.102377 | 789.997623 | 5.3063 | mm
025_head_fastener_m1_801_01.stl | head | head_fastener_m1_801 | silver | cosmetic exterior | 5.6 | 1.9 | 5.6 | -27.8 | -75.0 | 798.2 | 0.0468 | mm
026_head_fastener_m1_834_01.stl | head | head_fastener_m1_834 | silver | cosmetic exterior | 5.6 | 1.9 | 5.6 | -27.8 | -75.0 | 831.2 | 0.0468 | mm
027_head_service_plate_1_01.stl | head | head_service_plate_1 | graphite | cosmetic exterior | 62.005 | 1.603 | 54.005 | -38.002377 | 71.499301 | 789.997623 | 5.3063 | mm
028_head_fastener_1_801_01.stl | head | head_fastener_1_801 | silver | cosmetic exterior | 5.6 | 1.9 | 5.6 | -27.8 | 73.1 | 798.2 | 0.0468 | mm
029_head_fastener_1_834_01.stl | head | head_fastener_1_834 | silver | cosmetic exterior | 5.6 | 1.9 | 5.6 | -27.8 | 73.1 | 831.2 | 0.0468 | mm
030_lidar_pedestal_01.stl | head | lidar_pedestal | graphite | cosmetic exterior | 36.0 | 36.0 | 11.0 | -24.0 | -18.0 | 874.0 | 11.1966 | mm
031_lidar_base_01.stl | head | lidar_base | graphite | cosmetic exterior | 64.045 | 64.045 | 5.045 | -38.022378 | -32.022378 | 883.477622 | 14.5581 | mm
032_lidar_upper_cap_01.stl | head | lidar_upper_cap | graphite | lidar housing mock-up; cap needs a transparent support for display | 62.043 | 62.043 | 6.043 | -37.021678 | -31.021678 | 908.378322 | 18.1144 | mm
033_lidar_cap_trim_01.stl | head | lidar_cap_trim | copper | cosmetic exterior | 62.444 | 62.444 | 2.044 | -37.221818 | -31.221818 | 908.978182 | 0.0782 | mm
034_left_thigh_shell_01.stl | left_thigh | left_thigh_shell | silver | cosmetic exterior | 39.0 | 78.0 | 155.0 | -39.0 | 36.0 | 283.0 | 41.267 | mm
034_left_thigh_shell_02.stl | left_thigh | left_thigh_shell | silver | cosmetic exterior | 39.0 | 78.0 | 155.0 | -0.0 | 36.0 | 283.0 | 41.267 | mm
035_left_shin_shell_01.stl | left_shin | left_shin_shell | silver | cosmetic exterior | 34.0 | 68.0 | 158.0 | -34.0 | 41.0 | 88.0 | 36.7 | mm
035_left_shin_shell_02.stl | left_shin | left_shin_shell | silver | cosmetic exterior | 34.0 | 68.0 | 158.0 | -0.0 | 41.0 | 88.0 | 36.7 | mm
036_left_hip_hub_01.stl | left_thigh | left_hip_hub | graphite | visual joint cover; not a bearing | 42.0 | 29.0 | 42.0 | -21.0 | 46.0 | 439.0 | 16.8546 | mm
036_left_hip_hub_02.stl | left_thigh | left_hip_hub | graphite | visual joint cover; not a bearing | 42.0 | 29.0 | 42.0 | -21.0 | 75.0 | 439.0 | 16.8546 | mm
037_left_hip_disc_01.stl | left_thigh | left_hip_disc | bright_silver | cosmetic exterior | 28.02 | 4.02 | 28.02 | -14.00979 | 104.99021 | 445.99021 | 2.463 | mm
038_left_hip_bolt_01.stl | left_thigh | left_hip_bolt | graphite | cosmetic exterior | 11.0 | 3.5 | 11.0 | -5.5 | 109.0 | 454.5 | 0.3326 | mm
039_left_knee_hub_01.stl | left_shin | left_knee_hub | graphite | visual joint cover; not a bearing | 42.0 | 29.0 | 42.0 | -21.0 | 46.0 | 244.0 | 16.8546 | mm
039_left_knee_hub_02.stl | left_shin | left_knee_hub | graphite | visual joint cover; not a bearing | 42.0 | 29.0 | 42.0 | -21.0 | 75.0 | 244.0 | 16.8546 | mm
040_left_knee_disc_01.stl | left_shin | left_knee_disc | bright_silver | cosmetic exterior | 28.02 | 4.02 | 28.02 | -14.00979 | 104.99021 | 250.99021 | 2.463 | mm
041_left_knee_bolt_01.stl | left_shin | left_knee_bolt | graphite | cosmetic exterior | 11.0 | 3.5 | 11.0 | -5.5 | 109.0 | 259.5 | 0.3326 | mm
042_left_ankle_hub_01.stl | left_foot | left_ankle_hub | graphite | visual joint cover; not a bearing | 42.0 | 29.0 | 42.0 | -21.0 | 46.0 | 49.0 | 16.8546 | mm
042_left_ankle_hub_02.stl | left_foot | left_ankle_hub | graphite | visual joint cover; not a bearing | 42.0 | 29.0 | 42.0 | -21.0 | 75.0 | 49.0 | 16.8546 | mm
043_left_ankle_disc_01.stl | left_foot | left_ankle_disc | bright_silver | cosmetic exterior | 28.02 | 4.02 | 28.02 | -14.00979 | 104.99021 | 55.99021 | 2.463 | mm
044_left_ankle_bolt_01.stl | left_foot | left_ankle_bolt | graphite | cosmetic exterior | 11.0 | 3.5 | 11.0 | -5.5 | 109.0 | 64.5 | 0.3326 | mm
045_left_boot_shell_01.stl | left_foot | left_boot_shell | silver | cosmetic exterior | 85.033 | 92.067 | 67.067 | -62.533278 | 28.966722 | -0.033278 | 64.3983 | mm
045_left_boot_shell_02.stl | left_foot | left_boot_shell | silver | cosmetic exterior | 85.033 | 92.067 | 67.067 | 22.5 | 28.966722 | -0.033278 | 66.1261 | mm
046_left_sole_01.stl | left_foot | left_sole | rubber | cosmetic exterior | 163.012 | 87.012 | 6.012 | -59.005943 | 31.494057 | -0.005943 | 46.888 | mm
047_left_shin_band_123_01.stl | left_shin | left_shin_band_123 | bright_silver | cosmetic exterior | 34.0 | 68.0 | 7.0 | -34.0 | 41.0 | 119.5 | 1.7311 | mm
047_left_shin_band_123_02.stl | left_shin | left_shin_band_123 | bright_silver | cosmetic exterior | 34.0 | 68.0 | 7.0 | -0.0 | 41.0 | 119.5 | 1.7311 | mm
048_left_shin_band_169_01.stl | left_shin | left_shin_band_169 | bright_silver | cosmetic exterior | 34.0 | 68.0 | 7.0 | -34.0 | 41.0 | 165.5 | 1.4157 | mm
048_left_shin_band_169_02.stl | left_shin | left_shin_band_169 | bright_silver | cosmetic exterior | 34.0 | 68.0 | 7.0 | -0.0 | 41.0 | 165.5 | 1.4157 | mm
049_left_shin_band_215_01.stl | left_shin | left_shin_band_215 | bright_silver | cosmetic exterior | 34.0 | 68.0 | 7.0 | -34.0 | 41.0 | 211.5 | 0.58 | mm
049_left_shin_band_215_02.stl | left_shin | left_shin_band_215 | bright_silver | cosmetic exterior | 34.0 | 68.0 | 7.0 | -0.0 | 41.0 | 211.5 | 0.58 | mm
050_left_boot_nozzle_01.stl | left_foot | left_boot_nozzle | graphite | cosmetic exterior | 34.024 | 34.024 | 13.024 | 5.488112 | 57.988112 | 6.488112 | 4.3597 | mm
051_left_boot_nozzle_ring_01.stl | left_foot | left_boot_nozzle_ring | copper | cosmetic exterior | 38.027 | 38.027 | 4.027 | 3.486713 | 55.986713 | 6.986713 | 0.9048 | mm
052_left_shoulder_mount_01.stl | torso | left_shoulder_mount | graphite | shoulder support concept; not a qualified motor bracket | 24.019 | 68.019 | 25.019 | -24.009508 | 108.990492 | 690.490492 | 38.7243 | mm
053_left_shoulder_roll_yoke_rail_01.stl | left_shoulder_pitch_link | left_shoulder_roll_yoke_rail | graphite | joint-support rail concept | 10.236 | 31.221 | 33.234 | -18.517788 | 166.893792 | 674.882212 | 3.1006 | mm
054_left_shoulder_yaw_yoke_rail_01.stl | left_shoulder_roll_link | left_shoulder_yaw_yoke_rail | graphite | joint-support rail concept | 10.228 | 14.214 | 33.226 | -18.513901 | 187.890579 | 651.886099 | 2.4633 | mm
055_left_elbow_yoke_rail_01.stl | left_upper_arm | left_elbow_yoke_rail | graphite | joint-support rail concept | 10.224 | 10.224 | 114.223 | -18.512123 | 191.887877 | 547.887877 | 9.0538 | mm
056_left_forearm_roll_yoke_rail_01.stl | left_forearm | left_forearm_roll_yoke_rail | graphite | joint-support rail concept | 10.224 | 10.224 | 47.223 | -18.512123 | 191.887877 | 510.887877 | 3.579 | mm
057_left_wrist_pitch_yoke_rail_01.stl | left_forearm_roll_link | left_wrist_pitch_yoke_rail | graphite | joint-support rail concept | 10.224 | 10.224 | 89.223 | -18.512123 | 191.887877 | 431.887877 | 7.011 | mm
058_left_wrist_roll_yoke_rail_01.stl | left_wrist_pitch_link | left_wrist_roll_yoke_rail | graphite | joint-support rail concept | 10.224 | 10.224 | 30.223 | -18.512123 | 191.887877 | 411.887877 | 2.1899 | mm
059_left_thumb_support_01.stl | left_hand | left_thumb_support | graphite | cosmetic exterior | 15.014 | 20.014 | 13.014 | -7.507131 | 149.992869 | 389.492869 | 3.5653 | mm
060_left_shoulder_pitch_shaft_01.stl | left_shoulder_pitch_link | left_shoulder_pitch_shaft | silver | joint axle mock-up; use metal shaft on hardware | 6.004 | 36.004 | 6.004 | -3.002098 | 153.997902 | 699.997902 | 1.0179 | mm
061_left_shoulder_pitch_bearing_m1_01.stl | torso | left_shoulder_pitch_bearing_m1 | graphite | bearing race visual; substitute a purchased bearing | 20.305 | 4.0 | 28.0 | -6.30476 | 156.0 | 689.0 | 0.6805 | mm
062_left_shoulder_pitch_horn_m1_01.stl | left_shoulder_pitch_link | left_shoulder_pitch_horn_m1 | bright_silver | cosmetic exterior | 22.015 | 2.515 | 22.015 | -11.007692 | 153.242308 | 691.992308 | 0.4477 | mm
063_left_shoulder_pitch_screw_m1_0_01.stl | left_shoulder_pitch_link | left_shoulder_pitch_screw_m1_0 | black | fastener mock-up | 3.0 | 1.5 | 3.0 | -1.5 | 151.75 | 711.0 | 0.0106 | mm
064_left_shoulder_pitch_screw_m1_1_01.stl | left_shoulder_pitch_link | left_shoulder_pitch_screw_m1_1 | black | fastener mock-up | 3.0 | 1.5 | 3.0 | 8.0 | 151.75 | 701.5 | 0.0106 | mm
065_left_shoulder_pitch_screw_m1_2_01.stl | left_shoulder_pitch_link | left_shoulder_pitch_screw_m1_2 | black | fastener mock-up | 3.0 | 1.5 | 3.0 | -1.5 | 151.75 | 692.0 | 0.0106 | mm
066_left_shoulder_pitch_screw_m1_3_01.stl | left_shoulder_pitch_link | left_shoulder_pitch_screw_m1_3 | black | fastener mock-up | 3.0 | 1.5 | 3.0 | -11.0 | 151.75 | 701.5 | 0.0106 | mm
067_left_shoulder_pitch_bearing_1_01.stl | torso | left_shoulder_pitch_bearing_1 | graphite | bearing race visual; substitute a purchased bearing | 28.02 | 4.02 | 28.02 | -14.00979 | 183.99021 | 688.99021 | 1.2064 | mm
068_left_shoulder_pitch_horn_1_01.stl | left_shoulder_pitch_link | left_shoulder_pitch_horn_1 | bright_silver | cosmetic exterior | 22.015 | 2.515 | 22.015 | -11.007692 | 188.242308 | 691.992308 | 0.4477 | mm
069_left_shoulder_pitch_screw_1_0_01.stl | left_shoulder_pitch_link | left_shoulder_pitch_screw_1_0 | black | fastener mock-up | 3.0 | 1.5 | 3.0 | -1.5 | 190.75 | 711.0 | 0.0106 | mm
070_left_shoulder_pitch_screw_1_1_01.stl | left_shoulder_pitch_link | left_shoulder_pitch_screw_1_1 | black | fastener mock-up | 3.0 | 1.5 | 3.0 | 8.0 | 190.75 | 701.5 | 0.0106 | mm
071_left_shoulder_pitch_screw_1_2_01.stl | left_shoulder_pitch_link | left_shoulder_pitch_screw_1_2 | black | fastener mock-up | 3.0 | 1.5 | 3.0 | -1.5 | 190.75 | 692.0 | 0.0106 | mm
072_left_shoulder_pitch_screw_1_3_01.stl | left_shoulder_pitch_link | left_shoulder_pitch_screw_1_3 | black | fastener mock-up | 3.0 | 1.5 | 3.0 | -11.0 | 190.75 | 701.5 | 0.0106 | mm
073_left_shoulder_roll_shaft_01.stl | left_shoulder_roll_link | left_shoulder_roll_shaft | silver | joint axle mock-up; use metal shaft on hardware | 36.0 | 6.0 | 6.0 | -18.0 | 190.0 | 677.0 | 0.7555 | mm
074_left_shoulder_roll_bearing_m1_01.stl | left_shoulder_pitch_link | left_shoulder_roll_bearing_m1 | graphite | bearing race visual; substitute a purchased bearing | 4.0 | 28.0 | 28.0 | -16.0 | 179.0 | 666.0 | 1.0437 | mm
075_left_shoulder_roll_horn_m1_01.stl | left_shoulder_roll_link | left_shoulder_roll_horn_m1 | bright_silver | cosmetic exterior | 2.5 | 22.0 | 22.0 | -18.75 | 182.0 | 669.0 | 0.4066 | mm
076_left_shoulder_roll_screw_m1_0_01.stl | left_shoulder_roll_link | left_shoulder_roll_screw_m1_0 | black | fastener mock-up | 1.5 | 3.0 | 3.0 | -20.25 | 201.0 | 678.5 | 0.0106 | mm
077_left_shoulder_roll_screw_m1_1_01.stl | left_shoulder_roll_link | left_shoulder_roll_screw_m1_1 | black | fastener mock-up | 1.5 | 3.0 | 3.0 | -20.25 | 191.5 | 688.0 | 0.0106 | mm
078_left_shoulder_roll_screw_m1_2_01.stl | left_shoulder_roll_link | left_shoulder_roll_screw_m1_2 | black | fastener mock-up | 1.5 | 3.0 | 3.0 | -20.25 | 182.0 | 678.5 | 0.0106 | mm
079_left_shoulder_roll_screw_m1_3_01.stl | left_shoulder_roll_link | left_shoulder_roll_screw_m1_3 | black | fastener mock-up | 1.5 | 3.0 | 3.0 | -20.25 | 191.5 | 669.0 | 0.0106 | mm
080_left_shoulder_roll_bearing_1_01.stl | left_shoulder_pitch_link | left_shoulder_roll_bearing_1 | graphite | bearing race visual; substitute a purchased bearing | 4.02 | 28.02 | 28.02 | 11.99021 | 178.99021 | 665.99021 | 1.2064 | mm
081_left_shoulder_roll_horn_1_01.stl | left_shoulder_roll_link | left_shoulder_roll_horn_1 | bright_silver | cosmetic exterior | 2.515 | 22.015 | 22.015 | 16.242308 | 181.992308 | 668.992308 | 0.4477 | mm
082_left_shoulder_roll_screw_1_0_01.stl | left_shoulder_roll_link | left_shoulder_roll_screw_1_0 | black | fastener mock-up | 1.5 | 3.0 | 3.0 | 18.75 | 201.0 | 678.5 | 0.0106 | mm
083_left_shoulder_roll_screw_1_1_01.stl | left_shoulder_roll_link | left_shoulder_roll_screw_1_1 | black | fastener mock-up | 1.5 | 3.0 | 3.0 | 18.75 | 191.5 | 688.0 | 0.0106 | mm
084_left_shoulder_roll_screw_1_2_01.stl | left_shoulder_roll_link | left_shoulder_roll_screw_1_2 | black | fastener mock-up | 1.5 | 3.0 | 3.0 | 18.75 | 182.0 | 678.5 | 0.0106 | mm
085_left_shoulder_roll_screw_1_3_01.stl | left_shoulder_roll_link | left_shoulder_roll_screw_1_3 | black | fastener mock-up | 1.5 | 3.0 | 3.0 | 18.75 | 191.5 | 669.0 | 0.0106 | mm
086_left_shoulder_yaw_shaft_01.stl | left_upper_arm | left_shoulder_yaw_shaft | silver | joint axle mock-up; use metal shaft on hardware | 6.004 | 6.004 | 36.004 | -3.002098 | 193.997902 | 638.997902 | 1.0179 | mm
087_left_shoulder_yaw_bearing_m1_01.stl | left_shoulder_roll_link | left_shoulder_yaw_bearing_m1 | graphite | bearing race visual; substitute a purchased bearing | 28.02 | 28.02 | 4.02 | -14.00979 | 182.99021 | 640.99021 | 1.2064 | mm
088_left_shoulder_yaw_horn_m1_01.stl | left_upper_arm | left_shoulder_yaw_horn_m1 | bright_silver | cosmetic exterior | 21.244 | 22.0 | 2.511 | -10.244403 | 186.0 | 638.244406 | 0.4104 | mm
089_left_shoulder_yaw_screw_m1_0_01.stl | left_upper_arm | left_shoulder_yaw_screw_m1_0 | black | fastener mock-up | 3.0 | 3.0 | 1.5 | 8.0 | 195.5 | 636.75 | 0.0106 | mm
090_left_shoulder_yaw_screw_m1_1_01.stl | left_upper_arm | left_shoulder_yaw_screw_m1_1 | black | fastener mock-up | 3.0 | 3.0 | 1.5 | -1.5 | 205.0 | 636.75 | 0.0106 | mm
091_left_shoulder_yaw_screw_m1_2_01.stl | left_upper_arm | left_shoulder_yaw_screw_m1_2 | black | fastener mock-up | 0.404 | 2.048 | 1.5 | -8.403846 | 195.976063 | 636.75 | 0.0006 | mm
092_left_shoulder_yaw_screw_m1_3_01.stl | left_upper_arm | left_shoulder_yaw_screw_m1_3 | black | fastener mock-up | 3.0 | 3.0 | 1.5 | -1.5 | 186.0 | 636.75 | 0.0106 | mm
093_left_shoulder_yaw_bearing_1_01.stl | left_shoulder_roll_link | left_shoulder_yaw_bearing_1 | graphite | bearing race visual; substitute a purchased bearing | 27.797 | 28.0 | 4.0 | -13.796515 | 183.0 | 669.0 | 1.0629 | mm
094_left_shoulder_yaw_horn_1_01.stl | left_upper_arm | left_shoulder_yaw_horn_1 | bright_silver | cosmetic exterior | 22.015 | 22.015 | 2.515 | -11.007692 | 185.992308 | 673.242308 | 0.4477 | mm
095_left_shoulder_yaw_screw_1_0_01.stl | left_upper_arm | left_shoulder_yaw_screw_1_0 | black | fastener mock-up | 3.0 | 3.0 | 1.5 | 8.0 | 195.5 | 675.75 | 0.0106 | mm
096_left_shoulder_yaw_screw_1_1_01.stl | left_upper_arm | left_shoulder_yaw_screw_1_1 | black | fastener mock-up | 3.0 | 3.0 | 1.5 | -1.5 | 205.0 | 675.75 | 0.0106 | mm
097_left_shoulder_yaw_screw_1_2_01.stl | left_upper_arm | left_shoulder_yaw_screw_1_2 | black | fastener mock-up | 3.0 | 3.0 | 1.5 | -11.0 | 195.5 | 675.75 | 0.0106 | mm
098_left_shoulder_yaw_screw_1_3_01.stl | left_upper_arm | left_shoulder_yaw_screw_1_3 | black | fastener mock-up | 3.0 | 3.0 | 1.5 | -1.5 | 186.0 | 675.75 | 0.0106 | mm
099_left_elbow_shaft_01.stl | left_forearm | left_elbow_shaft | silver | joint axle mock-up; use metal shaft on hardware | 6.004 | 30.004 | 6.004 | -3.002098 | 181.997902 | 549.997902 | 0.8482 | mm
100_left_elbow_bearing_m1_01.stl | left_upper_arm | left_elbow_bearing_m1 | graphite | bearing race visual; substitute a purchased bearing | 20.014 | 4.014 | 20.014 | -10.006993 | 183.993007 | 542.993007 | 0.8042 | mm
101_left_elbow_horn_m1_01.stl | left_forearm | left_elbow_horn_m1 | bright_silver | cosmetic exterior | 14.01 | 2.51 | 14.01 | -7.004895 | 181.245105 | 545.995105 | 0.2592 | mm
102_left_elbow_screw_m1_0_01.stl | left_forearm | left_elbow_screw_m1_0 | black | fastener mock-up | 3.0 | 1.5 | 3.0 | -1.5 | 179.75 | 557.0 | 0.0106 | mm
103_left_elbow_screw_m1_1_01.stl | left_forearm | left_elbow_screw_m1_1 | black | fastener mock-up | 3.0 | 1.5 | 3.0 | 4.0 | 179.75 | 551.5 | 0.0106 | mm
104_left_elbow_screw_m1_2_01.stl | left_forearm | left_elbow_screw_m1_2 | black | fastener mock-up | 3.0 | 1.5 | 3.0 | -1.5 | 179.75 | 546.0 | 0.0106 | mm
105_left_elbow_screw_m1_3_01.stl | left_forearm | left_elbow_screw_m1_3 | black | fastener mock-up | 3.0 | 1.5 | 3.0 | -7.0 | 179.75 | 551.5 | 0.0106 | mm
106_left_elbow_bearing_1_01.stl | left_upper_arm | left_elbow_bearing_1 | graphite | bearing race visual; substitute a purchased bearing | 20.014 | 4.014 | 20.014 | -10.006993 | 205.993007 | 542.993007 | 0.8042 | mm
107_left_elbow_horn_1_01.stl | left_forearm | left_elbow_horn_1 | bright_silver | cosmetic exterior | 14.01 | 2.51 | 14.01 | -7.004895 | 210.245105 | 545.995105 | 0.2592 | mm
108_left_elbow_screw_1_0_01.stl | left_forearm | left_elbow_screw_1_0 | black | fastener mock-up | 3.0 | 1.5 | 3.0 | -1.5 | 212.75 | 557.0 | 0.0106 | mm
109_left_elbow_screw_1_1_01.stl | left_forearm | left_elbow_screw_1_1 | black | fastener mock-up | 3.0 | 1.5 | 3.0 | 4.0 | 212.75 | 551.5 | 0.0106 | mm
110_left_elbow_screw_1_2_01.stl | left_forearm | left_elbow_screw_1_2 | black | fastener mock-up | 3.0 | 1.5 | 3.0 | -1.5 | 212.75 | 546.0 | 0.0106 | mm
111_left_elbow_screw_1_3_01.stl | left_forearm | left_elbow_screw_1_3 | black | fastener mock-up | 3.0 | 1.5 | 3.0 | -7.0 | 212.75 | 551.5 | 0.0106 | mm
112_left_forearm_roll_shaft_01.stl | left_forearm_roll_link | left_forearm_roll_shaft | silver | joint axle mock-up; use metal shaft on hardware | 6.004 | 6.004 | 30.004 | -3.002098 | 193.997902 | 500.997902 | 0.8482 | mm
113_left_forearm_roll_bearing_m1_01.stl | left_forearm | left_forearm_roll_bearing_m1 | graphite | bearing race visual; substitute a purchased bearing | 20.014 | 20.014 | 4.014 | -10.006993 | 186.993007 | 502.993007 | 0.8042 | mm
114_left_forearm_roll_horn_m1_01.stl | left_forearm_roll_link | left_forearm_roll_horn_m1 | bright_silver | cosmetic exterior | 14.01 | 14.01 | 2.51 | -7.004895 | 189.995105 | 500.245105 | 0.2592 | mm
115_left_forearm_roll_screw_m1_0_01.stl | left_forearm_roll_link | left_forearm_roll_screw_m1_0 | black | fastener mock-up | 3.0 | 3.0 | 1.5 | 4.0 | 195.5 | 498.75 | 0.0106 | mm
116_left_forearm_roll_screw_m1_1_01.stl | left_forearm_roll_link | left_forearm_roll_screw_m1_1 | black | fastener mock-up | 3.0 | 3.0 | 1.5 | -1.5 | 201.0 | 498.75 | 0.0106 | mm
117_left_forearm_roll_screw_m1_2_01.stl | left_forearm_roll_link | left_forearm_roll_screw_m1_2 | black | fastener mock-up | 3.0 | 3.0 | 1.5 | -7.0 | 195.5 | 498.75 | 0.0106 | mm
118_left_forearm_roll_screw_m1_3_01.stl | left_forearm_roll_link | left_forearm_roll_screw_m1_3 | black | fastener mock-up | 3.0 | 3.0 | 1.5 | -1.5 | 190.0 | 498.75 | 0.0106 | mm
119_left_forearm_roll_bearing_1_01.stl | left_forearm | left_forearm_roll_bearing_1 | graphite | bearing race visual; substitute a purchased bearing | 19.461 | 20.0 | 4.008 | -9.460821 | 187.0 | 524.995804 | 0.7743 | mm
120_left_forearm_roll_horn_1_01.stl | left_forearm_roll_link | left_forearm_roll_horn_1 | bright_silver | cosmetic exterior | 14.01 | 14.01 | 2.51 | -7.004895 | 189.995105 | 529.245105 | 0.2592 | mm
121_left_forearm_roll_screw_1_0_01.stl | left_forearm_roll_link | left_forearm_roll_screw_1_0 | black | fastener mock-up | 3.0 | 3.0 | 1.5 | 4.0 | 195.5 | 531.75 | 0.0106 | mm
122_left_forearm_roll_screw_1_1_01.stl | left_forearm_roll_link | left_forearm_roll_screw_1_1 | black | fastener mock-up | 3.0 | 3.0 | 1.5 | -1.5 | 201.0 | 531.75 | 0.0106 | mm
123_left_forearm_roll_screw_1_2_01.stl | left_forearm_roll_link | left_forearm_roll_screw_1_2 | black | fastener mock-up | 3.0 | 3.0 | 1.5 | -7.0 | 195.5 | 531.75 | 0.0106 | mm
124_left_forearm_roll_screw_1_3_01.stl | left_forearm_roll_link | left_forearm_roll_screw_1_3 | black | fastener mock-up | 3.0 | 3.0 | 1.5 | -1.5 | 190.0 | 531.75 | 0.0106 | mm
125_left_wrist_pitch_shaft_01.stl | left_wrist_pitch_link | left_wrist_pitch_shaft | silver | joint axle mock-up; use metal shaft on hardware | 6.004 | 30.004 | 6.004 | -3.002098 | 181.997902 | 433.997902 | 0.8482 | mm
126_left_wrist_pitch_bearing_m1_01.stl | left_forearm_roll_link | left_wrist_pitch_bearing_m1 | graphite | bearing race visual; substitute a purchased bearing | 20.014 | 4.014 | 20.014 | -10.006993 | 183.993007 | 426.993007 | 0.8042 | mm
127_left_wrist_pitch_horn_m1_01.stl | left_wrist_pitch_link | left_wrist_pitch_horn_m1 | bright_silver | cosmetic exterior | 14.01 | 2.51 | 14.01 | -7.004895 | 181.245105 | 429.995105 | 0.2592 | mm
128_left_wrist_pitch_screw_m1_0_01.stl | left_wrist_pitch_link | left_wrist_pitch_screw_m1_0 | black | fastener mock-up | 3.0 | 1.5 | 3.0 | -1.5 | 179.75 | 441.0 | 0.0106 | mm
129_left_wrist_pitch_screw_m1_1_01.stl | left_wrist_pitch_link | left_wrist_pitch_screw_m1_1 | black | fastener mock-up | 3.0 | 1.5 | 3.0 | 4.0 | 179.75 | 435.5 | 0.0106 | mm
130_left_wrist_pitch_screw_m1_2_01.stl | left_wrist_pitch_link | left_wrist_pitch_screw_m1_2 | black | fastener mock-up | 3.0 | 1.5 | 3.0 | -1.5 | 179.75 | 430.0 | 0.0106 | mm
131_left_wrist_pitch_screw_m1_3_01.stl | left_wrist_pitch_link | left_wrist_pitch_screw_m1_3 | black | fastener mock-up | 3.0 | 1.5 | 3.0 | -7.0 | 179.75 | 435.5 | 0.0106 | mm
132_left_wrist_pitch_bearing_1_01.stl | left_forearm_roll_link | left_wrist_pitch_bearing_1 | graphite | bearing race visual; substitute a purchased bearing | 20.014 | 4.014 | 20.014 | -10.006993 | 205.993007 | 426.993007 | 0.8042 | mm
133_left_wrist_pitch_horn_1_01.stl | left_wrist_pitch_link | left_wrist_pitch_horn_1 | bright_silver | cosmetic exterior | 14.01 | 2.51 | 14.01 | -7.004895 | 210.245105 | 429.995105 | 0.2592 | mm
134_left_wrist_pitch_screw_1_0_01.stl | left_wrist_pitch_link | left_wrist_pitch_screw_1_0 | black | fastener mock-up | 3.0 | 1.5 | 3.0 | -1.5 | 212.75 | 441.0 | 0.0106 | mm
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

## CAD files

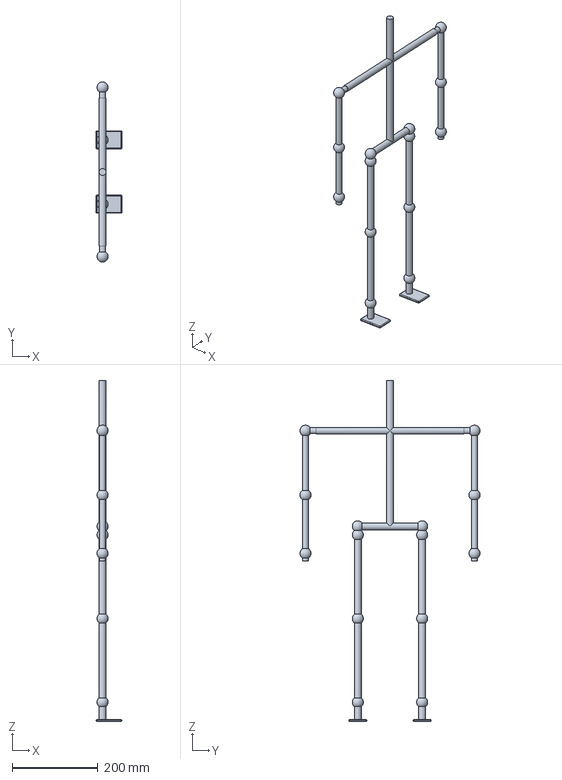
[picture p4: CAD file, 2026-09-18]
cad/static_display_armature.step
60.0 x 420.0 x 795.0 mm

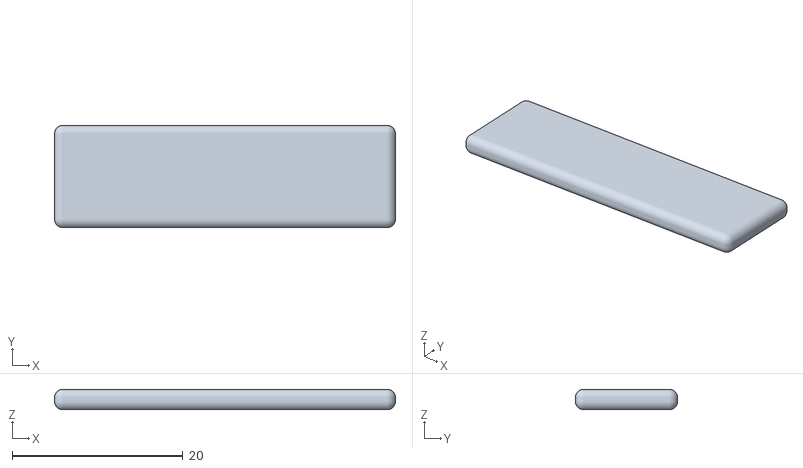
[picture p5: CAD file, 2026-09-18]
print/display_armature/seam_strap_print_as_needed.stl
40.0 x 12.0 x 2.40

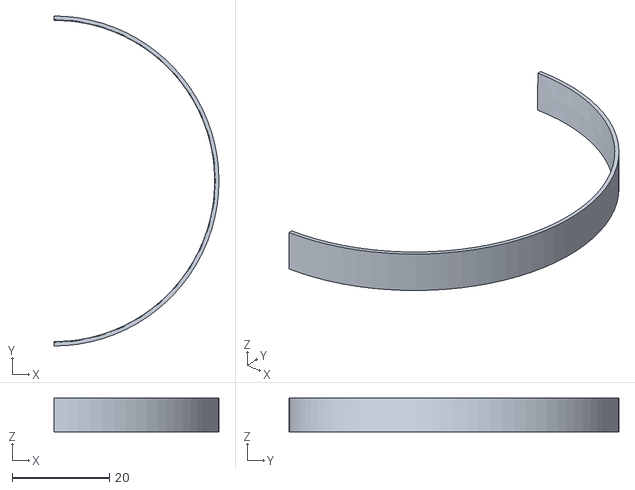
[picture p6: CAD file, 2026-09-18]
print/stl/049_left_shin_band_215_02.stl
34.0 x 68.0 x 7.00

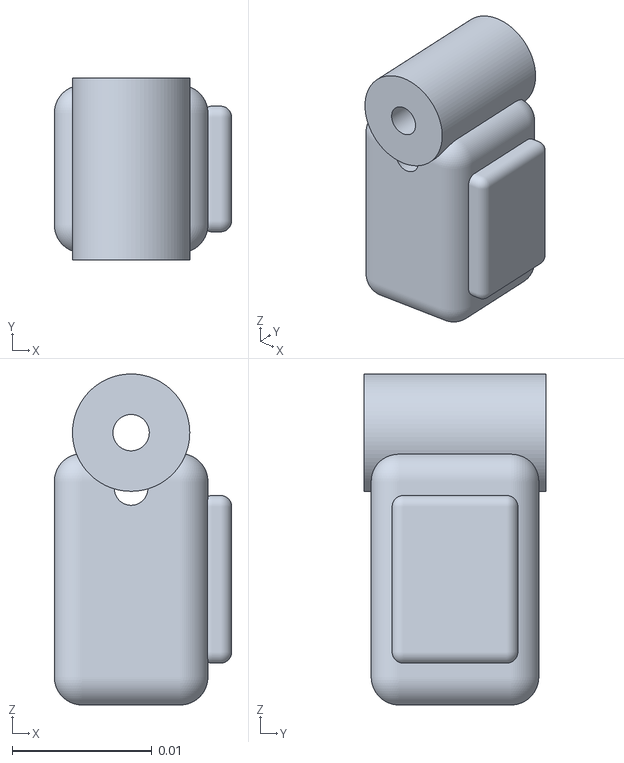
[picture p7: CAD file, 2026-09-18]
ros2/irona_sim/meshes/right_middle_pip_link.stl
0.0127 x 0.013 x 0.0237

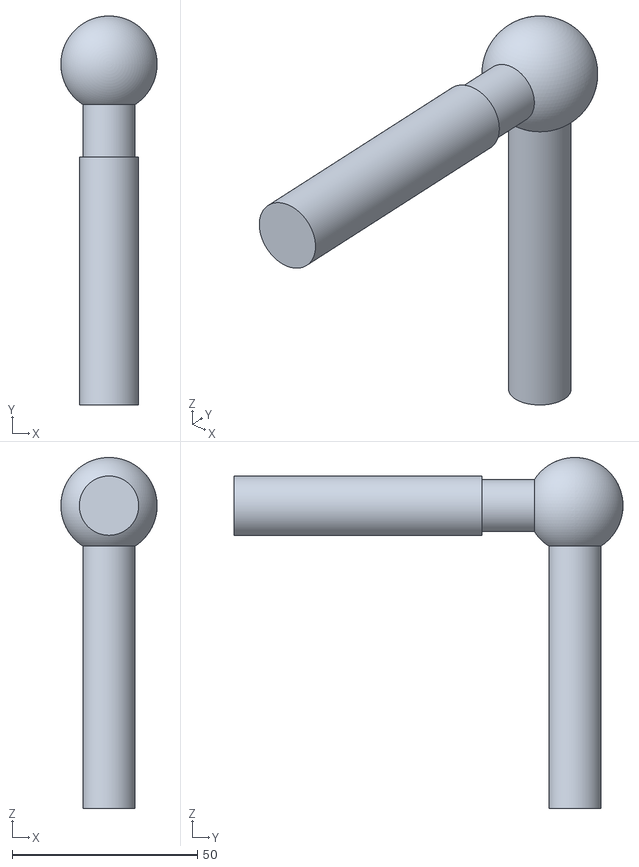
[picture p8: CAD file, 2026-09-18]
print/display_armature/display_core_14.stl
26.0 x 105.0 x 94.8

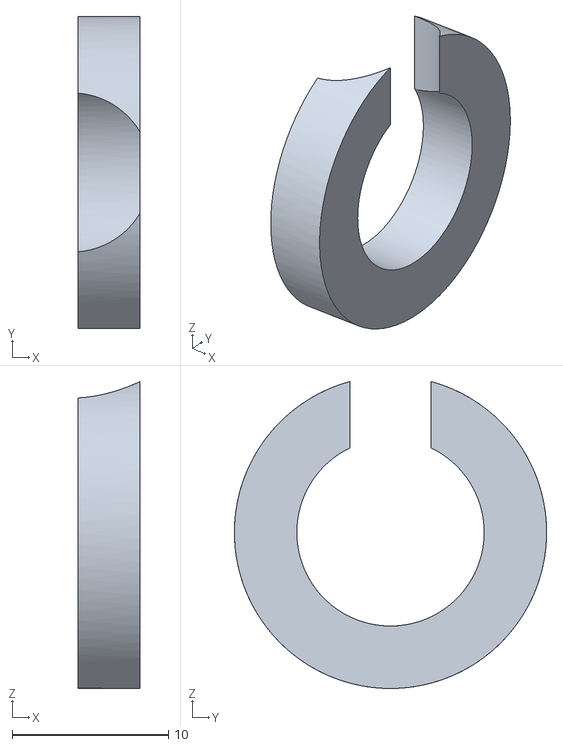
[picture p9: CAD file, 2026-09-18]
print/stl/315_right_wrist_roll_bearing_m1_01.stl
4.00 x 20.0 x 19.7

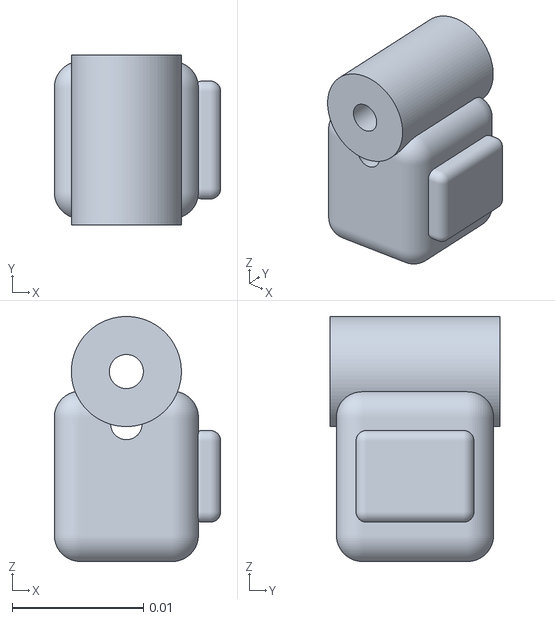
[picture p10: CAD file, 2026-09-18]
ros2/irona_sim/meshes/right_little_pip_link.stl
0.0127 x 0.013 x 0.0187

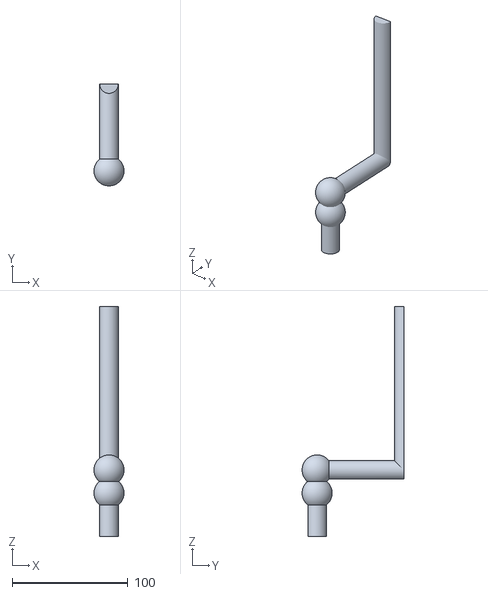
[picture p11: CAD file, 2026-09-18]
print/display_armature/display_core_05.stl
26.0 x 88.0 x 198.8

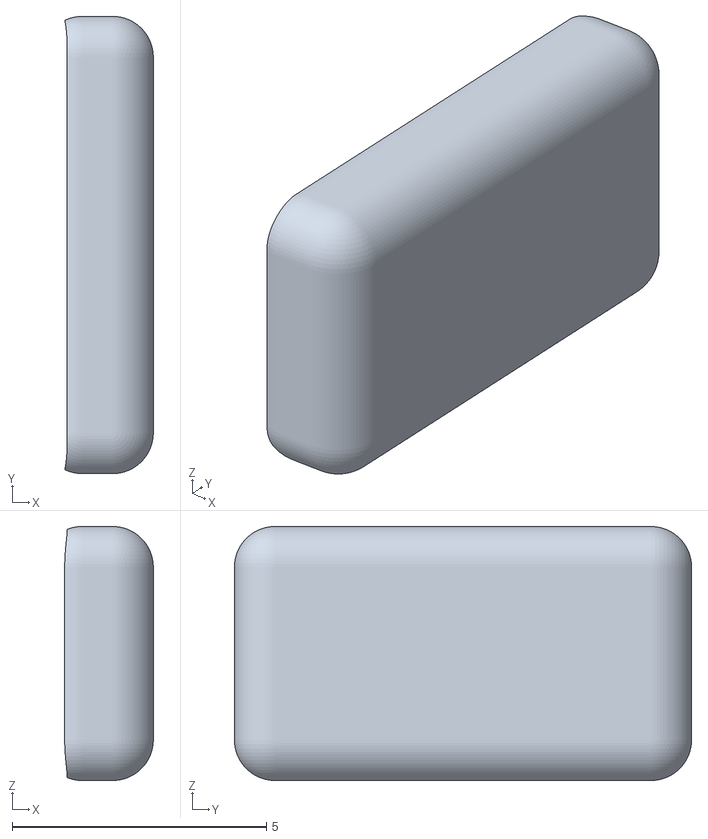
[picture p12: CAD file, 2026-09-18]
print/stl/343_right_index_dip_pad_01.stl
1.74 x 9.00 x 5.00

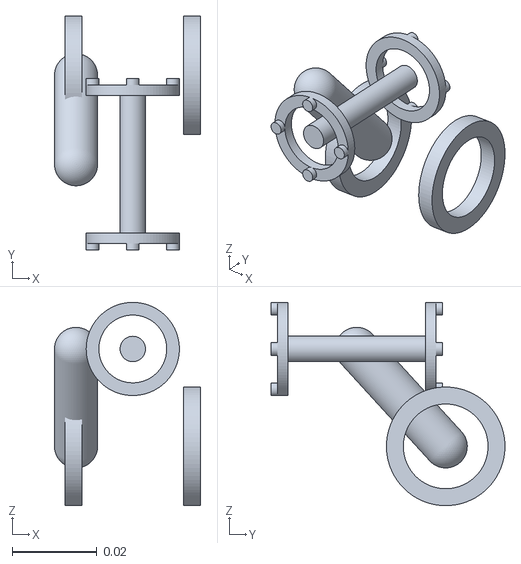
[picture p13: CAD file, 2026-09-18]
ros2/irona_sim/meshes/left_shoulder_pitch_link.stl
0.0345 x 0.0553 x 0.048

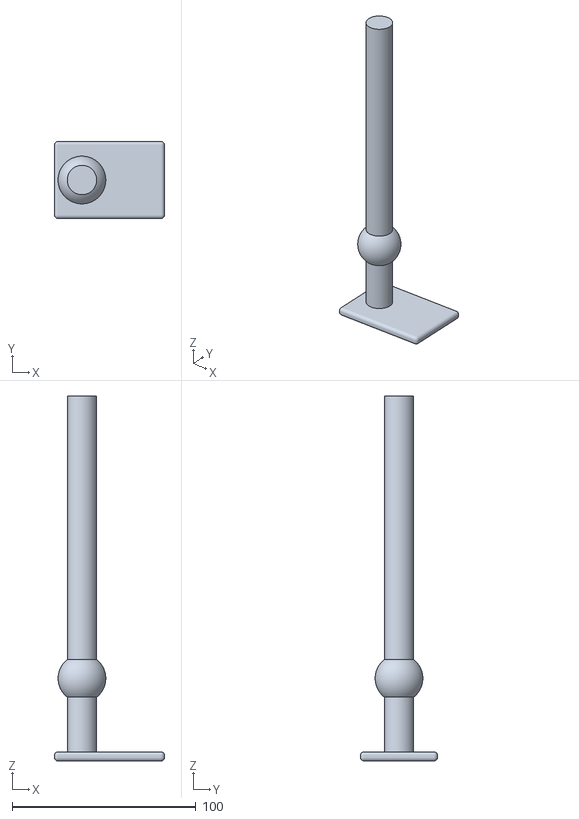
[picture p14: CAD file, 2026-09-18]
print/display_armature/display_core_09.stl
60.0 x 42.0 x 198.8

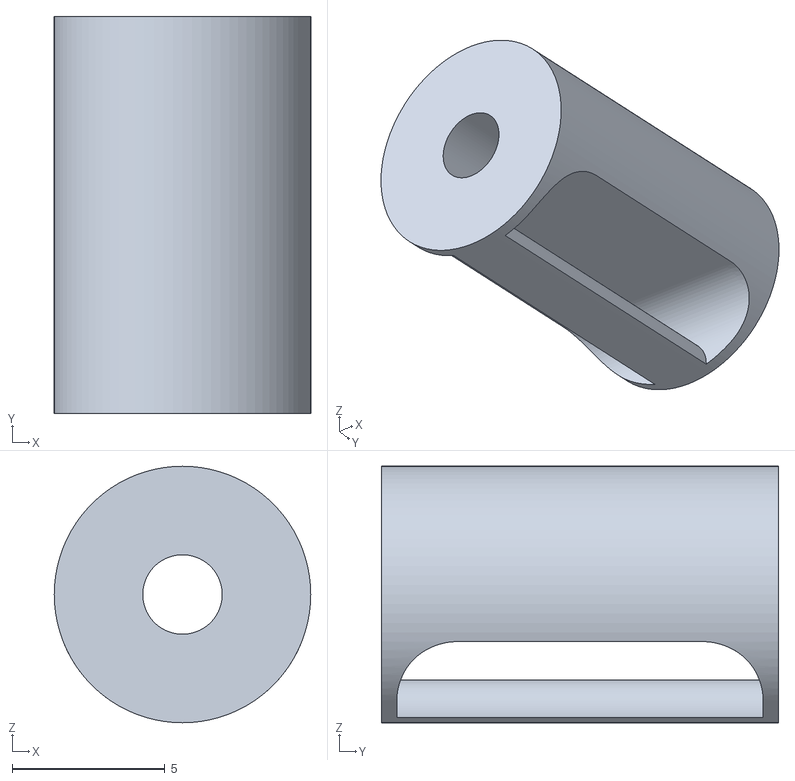
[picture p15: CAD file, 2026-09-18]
print/stl/341_right_index_pip_knuckle_01.stl
8.40 x 13.0 x 8.40

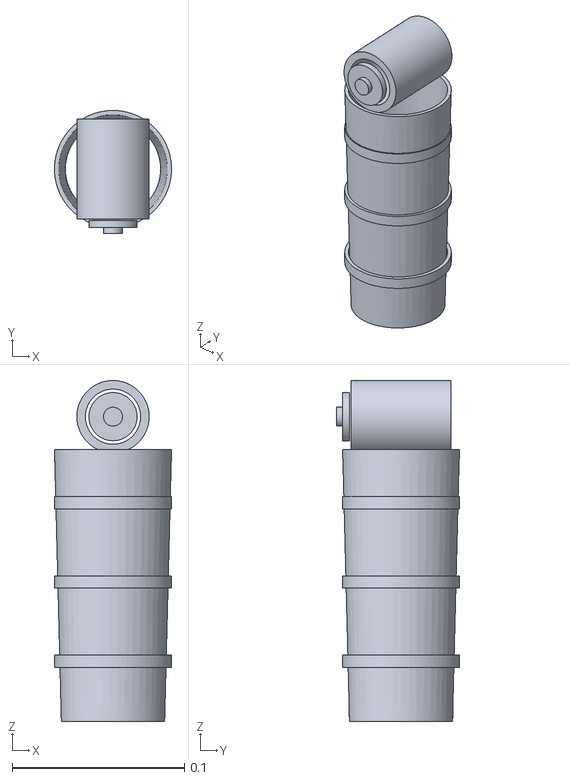
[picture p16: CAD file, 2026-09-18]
ros2/irona_sim/meshes/right_shin.stl
0.068 x 0.0715 x 0.198

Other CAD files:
ros2/install/irona_sim/share/irona_sim/meshes/pelvis.stl
ros2/install/irona_sim/share/irona_sim/meshes/head.stl
ros2/install/irona_sim/share/irona_sim/meshes/right_thigh.stl
ros2/install/irona_sim/share/irona_sim/meshes/right_forearm_roll_link.stl
print/display_armature/display_core_07.stl
print/display_armature/16mm_core_sleeve_print_as_needed.stl
print/display_armature/display_core_01.stl
print/display_armature/display_core_02.stl
print/display_armature/display_core_04.stl
print/display_armature/display_core_06.stl
print/display_armature/display_core_08.stl
print/display_armature/display_core_10.stl
print/display_armature/display_core_11.stl
print/display_armature/display_core_12.stl
print/display_armature/display_core_13.stl
print/stl/001_pelvis_shell_01.stl
print/stl/001_pelvis_shell_02.stl
print/stl/002_skirt_01.stl
print/stl/002_skirt_02.stl
print/stl/002_skirt_03.stl
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

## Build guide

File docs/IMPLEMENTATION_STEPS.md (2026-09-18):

# Implemented changes, step by step

1. **Replaced the old arm/gripper kinematic chains.** Added seven revolute axes per arm and removed the one-axis prismatic grippers. Shoulder axes now have distinct spatial offsets, with forearm rotation and a two-axis wrist. All physics, control and URDF definitions derive from `source/model.py`.
2. **Built two five-finger hands.** Each index/middle/ring/little finger has MCP, PIP and DIP joints. Each thumb has opposition, spread, MCP and IP joints. Added 32 hand joints with individual limits, masses, COMs, inertias and collision bodies.
3. **Rebuilt visible joints.** Added bearing-ring geometry, through shafts, horn rings, fastener details, separate phalanges, finger pads, palm housings and forearm tendon-port details. These are linked to the correct moving bodies in USD.
4. **Revised actuator assumptions.** Replaced the oversized original arm torque caps with XM540/XM430-informed design limits; added XL330-inspired virtual hand-drive caps, explicit speed limits and nominal PhysX joint friction. Catalog stall values are distinguished from design operating assumptions.
5. **Added hand motion controls.** Implemented smooth opening/closing poses, thumb opposition, a `hands` demo and a joint-target rate limiter. A ROS command subscriber accepts named arm/hand position targets, rejects malformed/nonfinite data and clips valid commands to range and rate limits.
6. **Removed the face.** Deleted eyes, pupils, highlights, eyebrows, nose, mouth, teeth, hair and cap. Rebuilt an expressionless silver head with a dark D455-style camera bar and service panels.
7. **Added native camera prims.** Authored color, depth and right-IR reference cameras directly into USD, with nominal D455 dimensions/baseline, clip ranges, aperture/focal settings and optical origins outside the front panel. Published color/depth are ideal rendered streams; right-IR remains a geometry reference.
8. **Added native 360° 3D lidar.** Authored an `OmniLidar` prim with a 32-channel emitter state, 360° horizontal coverage, 30° vertical span, 10 Hz rotation and full-scan point-cloud publication. The scan origin sits above the head shell. The lidar cap preserves the exact three-foot height.
9. **Added ROS 2 bridge graphs.** Created state, color, depth and lidar graph specifications using Isaac 5.x ROS helper nodes. The graph USD is included; the runtime reconstructs it using OmniGraph registration. It publishes RGB, depth, camera info, depth points, lidar points, clock, joint states and the floating-root transform.
10. **Added matching ROS TF and URDF.** Generated a 62-joint URDF, per-link visual meshes and fixed optical/lidar frames from the same source. Isaac owns world-to-pelvis TF; robot_state_publisher owns the rest. ROS and USD camera axis conventions are explicitly reconciled.
11. **Added complete launch files.** The relocatable `irona_sim` ament package includes `irona_sim.launch.py`, `sensors.launch.py`, `camera.launch.py` and `lidar.launch.py`. Launch arguments select modes, sensors, domain ID, runtime path, duration, headless rendering, arena and RViz.
12. **Added RViz visualization.** Supplied a saved display configuration with RobotModel, lidar/depth point clouds, color/depth images, optional TF and a world grid. Simulation time and compatible sensor QoS are configured.
13. **Added a perception arena.** Simple local targets in all four directions let the robot observe depth and lidar returns immediately without downloading an environment asset.
14. **Retained bipedal and flying dynamics.** Updated and reran the flat-floor walking, standing and four-thruster flight checks after changing mass distribution and arms. Flight still applies real simulated wrenches with saturation and response lag, without kinematic root motion.
15. **Regenerated fabrication files.** Rebuilt STEP, USD, numbered millimetre STL parts, assembly translations and static display supports. Removed stale face/gripper parts from the generated output. Validated printable mesh closure and size; no physical print or powered hardware fit is claimed.
16. **Added cross-format and live tests.** Offline checks cover joint agreement, optics, lidar arrays, graph wiring, source syntax and RViz YAML. The separate ROS acceptance script checks real received messages, timestamps, TF, camera intrinsics and lidar 3D coverage when run on your Isaac workstation.
17. **Updated documentation and previews.** Added sensor/TF and actuator guides, launch commands, current validation records and renders of the actual revised geometry. The downloadable archive includes the source needed to reproduce the generated assets.

## What remains unverified

Isaac Sim/PhysX execution, RTX rendering, ROS DDS transport and RViz display behavior were not run in the authoring environment. Current automated dynamics evidence is from MuJoCo and simplified collision geometry. A motorized physical chassis, working printed fingers, calibrated sensors and a real flying airframe are not established by these files.

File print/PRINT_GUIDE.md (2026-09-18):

# Irona 914 — printing and static assembly

## Scope and scale

Print at **100% scale, millimetres**. The fully assembled neutral exterior is
914.4 mm high. STL files contain only geometry and cannot enforce a unit system;
select mm in the slicer if prompted. USD uses metres and should not be sent
directly to a slicer.

This kit is suitable for a glued, static display and for evaluating cosmetic
surfaces around a future robot chassis. Its joints are visual covers and its
nozzles are decorative. It does not contain actuator mounts, working bearings,
qualified working five-finger linkages or operating jet hardware.

## Before printing the full kit

1. Open `cad/irona_exterior.step` in a STEP-capable CAD viewer. The model is already
   assembled, in mm, with named components.
2. Read `parts.csv` to identify the numbered shell files and desired colours.
   Every exported part has been checked for closed mesh geometry and an envelope
   no larger than 200 mm per axis. Check the slicer's brim and support footprint.
3. Start with one shin half and a joint cover. Check wall quality, dimensional
   accuracy and the appearance of the seam before committing to all parts.
4. Dry-fit a pair of shell halves and a core sleeve. The cosmetic seating cuts
   are nominal, with no printer-specific fit allowance. Sand or adjust CAD for
   your printer rather than forcing a tight assembly.

Suggested starting settings for a static indoor display: 0.4 mm nozzle, 0.2 mm
layers and PLA or PETG. The large cosmetic skins already have walls in the CAD;
use enough perimeters to fill those walls. The static core can use 4–6 perimeters
and moderate infill. These are slicing starting points, not strength ratings.
Orient broad split faces down where possible. Curved interiors, finger knuckles, sensor housings and
some joint covers may need supports. Individual parts have not been physically
printed or individually optimized for support-free manufacture.

## Assembly references

The frame is +X forward, +Y the robot's left, +Z up. Names such as `left_shin`
refer to the robot's left. The `parts.csv` translations reconstruct each STL's
position in the CAD assembly: add the three `assembly_t*_mm` values to its
vertices. No rotations are required. All STLs are translated to positive local
coordinates for slicing, so importing them all at the origin will not assemble
the robot automatically.

`assembly_transforms.json` contains the same exterior translations.
`display_armature/transforms.json` contains the separate core segment positions.
The two STEP files provide the full exterior and armature references.

## Static display build order

1. Glue the segmented static armature in the neutral pose shown in its STEP file.
   Align its spine, shoulder bar, pelvis bar, arms and legs against the CAD
   dimensions. Use flat temporary jigs so the feet remain parallel.
2. Reinforce accessible 16 mm core-rod butt joints with the provided sleeve.
   Its nominal bore is 16.4 mm. Sand it to fit and bond it in place. The smaller
   arm rods and crossbar junctions require adhesive and local reinforcement.
3. Assemble boots and soles around the foot supports. The soles have cosmetic
   nozzle openings. Use a rigid display base or a discreet rear support to keep
   the tall display from tipping.
4. Fit the shin and thigh skins around the core. Use small foam or printed shims
   between the inner shell and core where needed. Dry-fit before bonding.
5. Assemble pelvis and skirt panels. Work upward to the torso, shoulder covers,
   arm shells, bearing details and palms.
6. Fit neck covers, neutral head halves and the camera-bar mock-up. Assemble the
   lidar base and top cap using a transparent spacer through the open scan band.
   Keep the final cap top at 914.4 mm. The CAD intentionally omits an opaque
   window around the sensor origin. Printed plastic is not an optical sensor window.
7. Assemble each five-finger hand in its open display pose. Finger phalanges,
   pads, knuckles and pin/fastener details are individually listed in the manifest.
   Small knuckle bores are 2.4 mm pilots, not a proven retained hinge mechanism.
   Use a jig, adhesive and local support for a static display. For movable fingers,
   resolve a metal-pin linkage and clearance in CAD before printing the full hand.
8. Fit backpack shells and decorative nozzle rings last, then finish seams.

The included `seam_strap_print_as_needed.stl` is a small glue-on reinforcement
strip for the inside of straight cosmetic seams. Print as many as the assembly
needs. It is not a structural load connector. Trim strips at tight corners and
keep them clear of mating features.

## Finishing and a future powered build

The colour labels in the CSV correspond to the render: silver, bright silver,
graphite, ivory and copper. Paint small details after bonding if separate parts
are inconvenient. Mating seats remove most same-link geometric overlap; glue
lines, tolerances, access and small spacers remain a physical prototyping task.

A powered version needs a separately designed frame with selected actuators and
bearings. Do not drill arbitrary motor holes into these covers and treat them as
load-bearing mounts. Once the frame and electronics exist, replace the assumed
simulation masses and inertias with measured or CAD-derived assembly values.
No polymer temperature specification or structural design is provided for real
jet exhaust. Keep the flying function in simulation for this version.

## New arm and sensor parts

The part manifest identifies prototype shafts, bearing races, horns, fasteners,
phalanges and sensor housings by role. Small screw details can be omitted from
printing and represented with paint or purchased hardware. The D455 housing,
optical windows and lidar body are envelope mock-ups. Remove mock-ups when
engineering mounts for real sensors; no mounting-hole compatibility is certified.

Print the four larger finger segments and one palm half first to check the small
bore/edge quality. A finer nozzle or resin process may reproduce small details
better. The source is parametric so you can thicken or simplify them. The neutral
static armature has been moved outward to the new arm centerlines; it does not
support powered arm motion and must not be installed into a moving simulation.

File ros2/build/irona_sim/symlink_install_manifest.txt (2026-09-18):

/home/varun/homerobot/Irona_914_IsaacSim_5x(1)/irona_914/ros2/install/irona_sim/share/irona_sim/launch/camera.launch.py
/home/varun/homerobot/Irona_914_IsaacSim_5x(1)/irona_914/ros2/install/irona_sim/share/irona_sim/launch/irona_sim.launch.py
/home/varun/homerobot/Irona_914_IsaacSim_5x(1)/irona_914/ros2/install/irona_sim/share/irona_sim/launch/lidar.launch.py
/home/varun/homerobot/Irona_914_IsaacSim_5x(1)/irona_914/ros2/install/irona_sim/share/irona_sim/launch/rviz.launch.py
/home/varun/homerobot/Irona_914_IsaacSim_5x(1)/irona_914/ros2/install/irona_sim/share/irona_sim/launch/sensors.launch.py
/home/varun/homerobot/Irona_914_IsaacSim_5x(1)/irona_914/ros2/install/irona_sim/share/irona_sim/rviz/irona.rviz
/home/varun/homerobot/Irona_914_IsaacSim_5x(1)/irona_914/ros2/install/irona_sim/share/irona_sim/urdf/irona.urdf
/home/varun/homerobot/Irona_914_IsaacSim_5x(1)/irona_914/ros2/install/irona_sim/share/irona_sim/meshes/head.stl
/home/varun/homerobot/Irona_914_IsaacSim_5x(1)/irona_914/ros2/install/irona_sim/share/irona_sim/meshes/left_foot.stl
/home/varun/homerobot/Irona_914_IsaacSim_5x(1)/irona_914/ros2/install/irona_sim/share/irona_sim/meshes/left_forearm.stl
/home/varun/homerobot/Irona_914_IsaacSim_5x(1)/irona_914/ros2/install/irona_sim/share/irona_sim/meshes/left_forearm_roll_link.stl
/home/varun/homerobot/Irona_914_IsaacSim_5x(1)/irona_914/ros2/install/irona_sim/share/irona_sim/meshes/left_hand.stl
/home/varun/homerobot/Irona_914_IsaacSim_5x(1)/irona_914/ros2/install/irona_sim/share/irona_sim/meshes/left_index_dip_link.stl
/home/varun/homerobot/Irona_914_IsaacSim_5x(1)/irona_914/ros2/install/irona_sim/share/irona_sim/meshes/left_index_mcp_link.stl
/home/varun/homerobot/Irona_914_IsaacSim_5x(1)/irona_914/ros2/install/irona_sim/share/irona_sim/meshes/left_index_pip_link.stl
/home/varun/homerobot/Irona_914_IsaacSim_5x(1)/irona_914/ros2/install/irona_sim/share/irona_sim/meshes/left_little_dip_link.stl
/home/varun/homerobot/Irona_914_IsaacSim_5x(1)/irona_914/ros2/install/irona_sim/share/irona_sim/meshes/left_little_mcp_link.stl
/home/varun/homerobot/Irona_914_IsaacSim_5x(1)/irona_914/ros2/install/irona_sim/share/irona_sim/meshes/left_little_pip_link.stl
/home/varun/homerobot/Irona_914_IsaacSim_5x(1)/irona_914/ros2/install/irona_sim/share/irona_sim/meshes/left_middle_dip_link.stl
/home/varun/homerobot/Irona_914_IsaacSim_5x(1)/irona_914/ros2/install/irona_sim/share/irona_sim/meshes/left_middle_mcp_link.stl
/home/varun/homerobot/Irona_914_IsaacSim_5x(1)/irona_914/ros2/install/irona_sim/share/irona_sim/meshes/left_middle_pip_link.stl
/home/varun/homerobot/Irona_914_IsaacSim_5x(1)/irona_914/ros2/install/irona_sim/share/irona_sim/meshes/left_ring_dip_link.stl
/home/varun/homerobot/Irona_914_IsaacSim_5x(1)/irona_914/ros2/install/irona_sim/share/irona_sim/meshes/left_ring_mcp_link.stl
/home/varun/homerobot/Irona_914_IsaacSim_5x(1)/irona_914/ros2/install/irona_sim/share/irona_sim/meshes/left_ring_pip_link.stl
/home/varun/homerobot/Irona_914_IsaacSim_5x(1)/irona_914/ros2/install/irona_sim/share/irona_sim/meshes/left_shin.stl
/home/varun/homerobot/Irona_914_IsaacSim_5x(1)/irona_914/ros2/install/irona_sim/share/irona_sim/meshes/left_shoulder_pitch_link.stl
/home/varun/homerobot/Irona_914_IsaacSim_5x(1)/irona_914/ros2/install/irona_sim/share/irona_sim/meshes/left_shoulder_roll_link.stl
/home/varun/homerobot/Irona_914_IsaacSim_5x(1)/irona_914/ros2/install/irona_sim/share/irona_sim/meshes/left_thigh.stl
/home/varun/homerobot/Irona_914_IsaacSim_5x(1)/irona_914/ros2/install/irona_sim/share/irona_sim/meshes/left_thumb_cmc_link.stl
/home/varun/homerobot/Irona_914_IsaacSim_5x(1)/irona_914/ros2/install/irona_sim/share/irona_sim/meshes/left_thumb_ip_link.stl
/home/varun/homerobot/Irona_914_IsaacSim_5x(1)/irona_914/ros2/install/irona_sim/share/irona_sim/meshes/left_thumb_mcp_link.stl
/home/varun/homerobot/Irona_914_IsaacSim_5x(1)/irona_914/ros2/install/irona_sim/share/irona_sim/meshes/left_thumb_spread_link.stl
/home/varun/homerobot/Irona_914_IsaacSim_5x(1)/irona_914/ros2/install/irona_sim/share/irona_sim/meshes/left_upper_arm.stl
/home/varun/homerobot/Irona_914_IsaacSim_5x(1)/irona_914/ros2/install/irona_sim/share/irona_sim/meshes/left_wrist_pitch_link.stl
/home/varun/homerobot/Irona_914_IsaacSim_5x(1)/irona_914/ros2/install/irona_sim/share/irona_sim/meshes/neck_yaw_link.stl
/home/varun/homerobot/Irona_914_IsaacSim_5x(1)/irona_914/ros2/install/irona_sim/share/irona_sim/meshes/pelvis.stl
/home/varun/homerobot/Irona_914_IsaacSim_5x(1)/irona_914/ros2/install/irona_sim/share/irona_sim/meshes/right_foot.stl
/home/varun/homerobot/Irona_914_IsaacSim_5x(1)/irona_914/ros2/install/irona_sim/share/irona_sim/meshes/right_forearm.stl
/home/varun/homerobot/Irona_914_IsaacSim_5x(1)/irona_914/ros2/install/irona_sim/share/irona_sim/meshes/right_forearm_roll_link.stl
/home/varun/homerobot/Irona_914_IsaacSim_5x(1)/irona_914/ros2/install/irona_sim/share/irona_sim/meshes/right_hand.stl
/home/varun/homerobot/Irona_914_IsaacSim_5x(1)/irona_914/ros2/install/irona_sim/share/irona_sim/meshes/right_index_dip_link.stl
/home/varun/homerobot/Irona_914_IsaacSim_5x(1)/irona_914/ros2/install/irona_sim/share/irona_sim/meshes/right_index_mcp_link.stl
/home/varun/homerobot/Irona_914_IsaacSim_5x(1)/irona_914/ros2/install/irona_sim/share/irona_sim/meshes/right_index_pip_link.stl
/home/varun/homerobot/Irona_914_IsaacSim_5x(1)/irona_914/ros2/install/irona_sim/share/irona_sim/meshes/right_little_dip_link.stl
/home/varun/homerobot/Irona_914_IsaacSim_5x(1)/irona_914/ros2/install/irona_sim/share/irona_sim/meshes/right_little_mcp_link.stl
/home/varun/homerobot/Irona_914_IsaacSim_5x(1)/irona_914/ros2/install/irona_sim/share/irona_sim/meshes/right_little_pip_link.stl
/home/varun/homerobot/Irona_914_IsaacSim_5x(1)/irona_914/ros2/install/irona_sim/share/irona_sim/meshes/right_middle_dip_link.stl
/home/varun/homerobot/Irona_914_IsaacSim_5x(1)/irona_914/ros2/install/irona_sim/share/irona_sim/meshes/right_middle_mcp_link.stl
/home/varun/homerobot/Irona_914_IsaacSim_5x(1)/irona_914/ros2/install/irona_sim/share/irona_sim/meshes/right_middle_pip_link.stl
/home/varun/homerobot/Irona_914_IsaacSim_5x(1)/irona_914/ros2/install/irona_sim/share/irona_sim/meshes/right_ring_dip_link.stl
/home/varun/homerobot/Irona_914_IsaacSim_5x(1)/irona_914/ros2/install/irona_sim/share/irona_sim/meshes/right_ring_mcp_link.stl
/home/varun/homerobot/Irona_914_IsaacSim_5x(1)/irona_914/ros2/install/irona_sim/share/irona_sim/meshes/right_ring_pip_link.stl
/home/varun/homerobot/Irona_914_IsaacSim_5x(1)/irona_914/ros2/install/irona_sim/share/irona_sim/meshes/right_shin.stl
/home/varun/homerobot/Irona_914_IsaacSim_5x(1)/irona_914/ros2/install/irona_sim/share/irona_sim/meshes/right_shoulder_pitch_link.stl
/home/varun/homerobot/Irona_914_IsaacSim_5x(1)/irona_914/ros2/install/irona_sim/share/irona_sim/meshes/right_shoulder_roll_link.stl
/home/varun/homerobot/Irona_914_IsaacSim_5x(1)/irona_914/ros2/install/irona_sim/share/irona_sim/meshes/right_thigh.stl
/home/varun/homerobot/Irona_914_IsaacSim_5x(1)/irona_914/ros2/install/irona_sim/share/irona_sim/meshes/right_thumb_cmc_link.stl
/home/varun/homerobot/Irona_914_IsaacSim_5x(1)/irona_914/ros2/install/irona_sim/share/irona_sim/meshes/right_thumb_ip_link.stl
/home/varun/homerobot/Irona_914_IsaacSim_5x(1)/irona_914/ros2/install/irona_sim/share/irona_sim/meshes/right_thumb_mcp_link.stl
/home/varun/homerobot/Irona_914_IsaacSim_5x(1)/irona_914/ros2/install/irona_sim/share/irona_sim/meshes/right_thumb_spread_link.stl
/home/varun/homerobot/Irona_914_IsaacSim_5x(1)/irona_914/ros2/install/irona_sim/share/irona_sim/meshes/right_upper_arm.stl
/home/varun/homerobot/Irona_914_IsaacSim_5x(1)/irona_914/ros2/install/irona_sim/share/irona_sim/meshes/right_wrist_pitch_link.stl
/home/varun/homerobot/Irona_914_IsaacSim_5x(1)/irona_914/ros2/install/irona_sim/share/irona_sim/meshes/torso.stl
/home/varun/homerobot/Irona_914_IsaacSim_5x(1)/irona_914/ros2/install/irona_sim/share/irona_sim/project/assets/irona.usd
/home/varun/homerobot/Irona_914_IsaacSim_5x(1)/irona_914/ros2/install/irona_sim/share/irona_sim/project/assets/irona.usda
/home/varun/homerobot/Irona_914_IsaacSim_5x(1)/irona_914/ros2/install/irona_sim/share/irona_sim/project/assets/ros2_bridge.usda
/home/varun/homerobot/Irona_914_IsaacSim_5x(1)/irona_914/ros2/install/irona_sim/share/irona_sim/project/assets/scene.usda
/home/varun/homerobot/Irona_914_IsaacSim_5x(1)/irona_914/ros2/install/irona_sim/share/irona_sim/project/assets/scene_ros.usda
/home/varun/homerobot/Irona_914_IsaacSim_5x(1)/irona_914/ros2/install/irona_sim/share/irona_sim/project/config/joint_limits.csv
/home/varun/homerobot/Irona_914_IsaacSim_5x(1)/irona_914/ros2/install/irona_sim/share/irona_sim/project/config/robot.json
/home/varun/homerobot/Irona_914_IsaacSim_5x(1)/irona_914/ros2/install/irona_sim/share/irona_sim/project/config/sensors.json
/home/varun/homerobot/Irona_914_IsaacSim_5x(1)/irona_914/ros2/install/irona_sim/share/irona_sim/project/source/arena.py
/home/varun/homerobot/Irona_914_IsaacSim_5x(1)/irona_914/ros2/install/irona_sim/share/irona_sim/project/source/build_assets.py
/home/varun/homerobot/Irona_914_IsaacSim_5x(1)/irona_914/ros2/install/irona_sim/share/irona_sim/project/source/build_ros_assets.py
/home/varun/homerobot/Irona_914_IsaacSim_5x(1)/irona_914/ros2/install/irona_sim/share/irona_sim/project/source/clean_print_meshes.py
/home/varun/homerobot/Irona_914_IsaacSim_5x(1)/irona_914/ros2/install/irona_sim/share/irona_sim/project/source/control.py
/home/varun/homerobot/Irona_914_IsaacSim_5x(1)/irona_914/ros2/install/irona_sim/share/irona_sim/project/source/model.py
/home/varun/homerobot/Irona_914_IsaacSim_5x(1)/irona_914/ros2/install/irona_sim/share/irona_sim/project/source/mujoco_check.py
/home/varun/homerobot/Irona_914_IsaacSim_5x(1)/irona_914/ros2/install/irona_sim/share/irona_sim/project/source/package_project.py
/home/varun/homerobot/Irona_914_IsaacSim_5x(1)/irona_914/ros2/install/irona_sim/share/irona_sim/project/source/render_dynamics.py
/home/varun/homerobot/Irona_914_IsaacSim_5x(1)/irona_914/ros2/install/irona_sim/share/irona_sim/project/source/render_hand_details.py
/home/varun/homerobot/Irona_914_IsaacSim_5x(1)/irona_914/ros2/install/irona_sim/share/irona_sim/project/source/render_previews.py
/home/varun/homerobot/Irona_914_IsaacSim_5x(1)/irona_914/ros2/install/irona_sim/share/irona_sim/project/source/ros_bridge.py
/home/varun/homerobot/Irona_914_IsaacSim_5x(1)/irona_914/ros2/install/irona_sim/share/irona_sim/project/source/run_isaac.py
/home/varun/homerobot/Irona_914_IsaacSim_5x(1)/irona_914/ros2/install/irona_sim/share/irona_sim/project/source/sensors.py
/home/varun/homerobot/Irona_914_IsaacSim_5x(1)/irona_914/ros2/install/irona_sim/share/irona_sim/project/source/validate_assets.py
/home/varun/homerobot/Irona_914_IsaacSim_5x(1)/irona_914/ros2/install/irona_sim/share/irona_sim/project/source/validate_revision.py
/home/varun/homerobot/Irona_914_IsaacSim_5x(1)/irona_914/ros2/install/irona_sim/lib/irona_sim/sensor_smoke_test.py
/home/varun/homerobot/Irona_914_IsaacSim_5x(1)/irona_914/ros2/install/irona_sim/lib/irona_sim/hand_command.py
/home/varun/homerobot/Irona_914_IsaacSim_5x(1)/irona_914/ros2/install/irona_sim/share/ament_index/resource_index/package_run_dependencies/irona_sim
/home/varun/homerobot/Irona_914_IsaacSim_5x(1)/irona_914/ros2/install/irona_sim/share/ament_index/resource_index/parent_prefix_path/irona_sim
/home/varun/homerobot/Irona_914_IsaacSim_5x(1)/irona_914/ros2/install/irona_sim/share/irona_sim/environment/ament_prefix_path.sh
/home/varun/homerobot/Irona_914_IsaacSim_5x(1)/irona_914/ros2/install/irona_sim/share/irona_sim/environment/ament_prefix_path.dsv
/home/varun/homerobot/Irona_914_IsaacSim_5x(1)/irona_914/ros2/install/irona_sim/share/irona_sim/environment/path.sh
/home/varun/homerobot/Irona_914_IsaacSim_5x(1)/irona_914/ros2/install/irona_sim/share/irona_sim/environment/path.dsv
/home/varun/homerobot/Irona_914_IsaacSim_5x(1)/irona_914/ros2/install/irona_sim/share/irona_sim/local_setup.bash
/home/varun/homerobot/Irona_914_IsaacSim_5x(1)/irona_914/ros2/install/irona_sim/share/irona_sim/local_setup.sh
/home/varun/homerobot/Irona_914_IsaacSim_5x(1)/irona_914/ros2/install/irona_sim/share/irona_sim/local_setup.zsh
/home/varun/homerobot/Irona_914_IsaacSim_5x(1)/irona_914/ros2/install/irona_sim/share/irona_sim/local_setup.dsv
/home/varun/homerobot/Irona_914_IsaacSim_5x(1)/irona_914/ros2/install/irona_sim/share/irona_sim/package.dsv
/home/varun/homerobot/Irona_914_IsaacSim_5x(1)/irona_914/ros2/install/irona_sim/share/ament_index/resource_index/packages/irona_sim
/home/varun/homerobot/Irona_914_IsaacSim_5x(1)/irona_914/ros2/install/irona_sim/share/irona_sim/cmake/irona_simConfig.cmake
/home/varun/homerobot/Irona_914_IsaacSim_5x(1)/irona_914/ros2/install/irona_sim/share/irona_sim/cmake/irona_simConfig-version.cmake
/home/varun/homerobot/Irona_914_IsaacSim_5x(1)/irona_914/ros2/install/irona_sim/share/irona_sim/package.xml

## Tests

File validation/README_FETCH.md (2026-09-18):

# Live run artefacts

- `isaac_fetch_mission.json` — the mission report from the last `--mode fetch`
  run: every state transition with its timestamp, the camera estimate of the vase,
  the aim point actually used, IK residuals, palm-correction count, the height the
  vase was lifted and whether the grasp assist engaged.
- `isaac_fetch_trajectory.json`, `isaac_walk_trajectory.json`,
  `isaac_stand_trajectory.json` — 20 Hz samples of pelvis pose, joint positions,
  centre of mass, tilt and (for fetch) the vase position and mission state.

These are overwritten by each run. `docs/ISAAC_RUN_NOTES.md` explains what the
numbers mean and the limits behind them.

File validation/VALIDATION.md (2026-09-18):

# Validation record — hands and perception revision

The revised model has 63 rigid bodies and 62 actuated joints. All original
standing, walking and flight reports were regenerated after the arm/hand/mass
changes. A hand-motion rollout was added. These runs use MuJoCo 3.13.0, not
Isaac Sim / PhysX.

## Current independent dynamics runs

| Mode | Simulation time (s) | Fell? | Forward displacement (m) | Maximum tilt (deg) | Peak joint torque (Nm) |
|---|---:|---|---:|---:|---:|
| stand | 6.0 | No | -0.0041 | 0.159 | 5.357 |
| walk | 24.0 | No | 0.3867 | 3.241 | 19.864 |
| hands | 8.0 | No | -0.0058 | 0.159 | 5.357 |
| flight | 16.0 | No | -0.0015 | 0.431 | 12.215 |

The revised 24-second walk traveled 0.3867 m forward with −0.0806 m lateral
sway/drift. The 16-second flight rose about 0.651 m and returned close to its
starting height. Peak summed jet force was 154.43 N. Walking uses joint drives
and ground contacts; flight uses external wrenches, not a prescribed root path.

Each mode's JSON report contains measured peak torques/speeds for all joints.
The corresponding trajectory includes root pose, joint positions, foot normal
forces, COM and thruster-force magnitudes. Physics dt is 0.001 s. Geometry-only
changes to joint covers/support rails do not change this proxy dynamics model.

## Asset and revision checks

Final geometry: 914.4000 mm tall. All 458 STL files passed mesh/bed-size checks:
442 exterior/detail parts and 16 static support/assembly aid files.

`asset_report.json` records the final measured height, print count, USD composition,
positive inertias, coincident joint anchors, ungrounded articulation, print-mesh
closure/size, leg IK and thrust-allocation rank. `revision_report.json` separately
checks all ten fingers, removal of facial features, camera forward/right/down
axes, 360-degree lidar emitter arrays, URDF agreement, graph connections, syntax
and RViz configuration. Read those generated reports for the authoritative
final file counts and pass/fail results.

The revised print parts are checked for watertight meshes, consistent winding,
positive volume and a maximum axis-aligned dimension of 200 mm. No physical
print or production tolerance test was performed.

## Runtime test supplied, but not run here

`ros2/irona_sim/scripts/sensor_smoke_test.py` is intended for the user's running
Isaac/ROS workstation. It checks actual images, CameraInfo, point clouds, clock,
all 62 joint positions and TF connectivity; with the default arena it also
checks lidar returns in all four quadrants and vertical 3D spread. No passing
ROS runtime report is fabricated or included.

The native graph layer and standalone source are checked against NVIDIA's
Isaac Sim 5.1 interfaces. Offline graph validation cannot establish that an
installed Isaac version will load every extension or publish data correctly.

## Scope limits

- Isaac/PhysX execution, RTX rendering, ROS transport and RViz behavior remain untested here.
- MuJoCo and PhysX use different contact solvers. The MuJoCo check does not reproduce the PhysX joint-friction coefficients.
- Full moving CAD clearance, hardware motor fit, real bearing supports, FEA, print tolerances, cable transmissions and power/thermal design are unverified.
- The hand demo demonstrates opening/closing in physics; no object grasp or manipulation success is claimed.
- The camera is ideal rendered RGB-D; the lidar is a generic configured model. Neither is a calibrated physical sensor emulator.
- The included video is an accelerated replay of recorded MuJoCo states using the CAD geometry. Thrust glyphs are illustrative, not exhaust-fluid simulation.

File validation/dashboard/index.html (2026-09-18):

# Irona 914 — run inspector

loading index.json…

## Camera frame

Colour, with the segmented vase outlined and the blob centroid marked

Rendered depth, near red to far blue

◀Play▶ 0.00 s

## Annotations

## Estimate error vs the true vase

horizontal error (mm)detected pixels

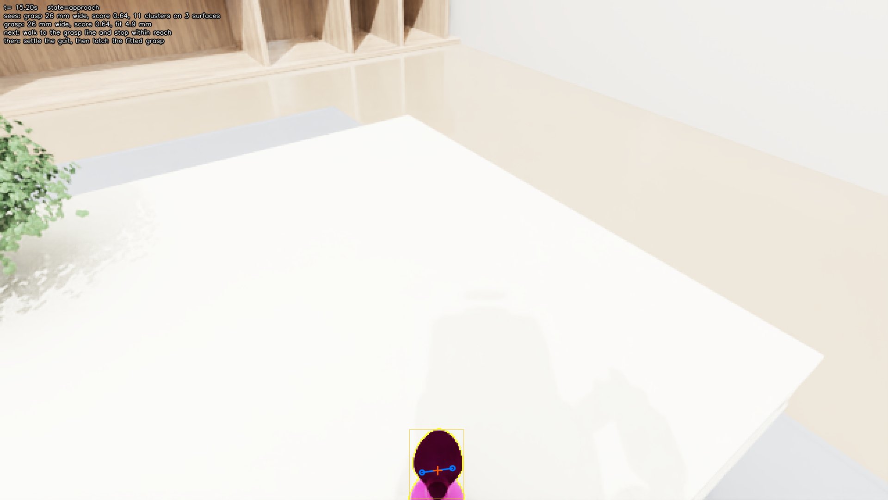
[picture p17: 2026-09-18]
validation/live/frame.jpg

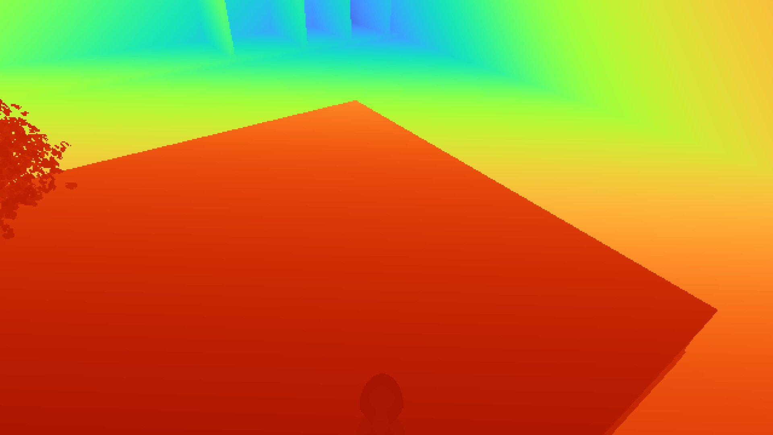
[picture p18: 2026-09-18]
validation/live/depth.jpg

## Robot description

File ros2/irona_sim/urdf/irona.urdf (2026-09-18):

<?xml version='1.0' encoding='utf-8'?>
<robot name="irona_914">
  <link name="pelvis">
    <inertial>
      <origin xyz="0 0 0.01" rpy="0 0 0" />
      <mass value="2.0" />
      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
    </inertial>
    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
  </link>
  <link name="waist_yaw_link">
    <inertial>
      <origin xyz="0 0 0" rpy="0 0 0" />
      <mass value="0.12" />
      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
    </inertial>
  </link>
  <link name="torso">
    <inertial>
      <origin xyz="-0.012 0 0.076" rpy="0 0 0" />
      <mass value="3.6" />
      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
    </inertial>
    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
  </link>
  <link name="neck_yaw_link">
    <inertial>
      <origin xyz="0 0 0" rpy="0 0 0" />
      <mass value="0.1" />
      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
    </inertial>
    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
  </link>
  <link name="head">
    <inertial>
      <origin xyz="0.01 0 0.069" rpy="0 0 0" />
      <mass value="0.91" />
      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
    </inertial>
    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
  </link>
  <link name="left_hip_yaw_link">
    <inertial>
      <origin xyz="0 0 0" rpy="0 0 0" />
      <mass value="0.1" />
      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
    </inertial>
  </link>
  <link name="left_hip_roll_link">
    <inertial>
      <origin xyz="0 0 0" rpy="0 0 0" />
      <mass value="0.15" />
      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
    </inertial>
  </link>
  <link name="left_thigh">
    <inertial>
      <origin xyz="0 0 -0.095" rpy="0 0 0" />
      <mass value="0.95" />
      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
    </inertial>
    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
  </link>
  <link name="left_shin">
    <inertial>
      <origin xyz="0 0 -0.094" rpy="0 0 0" />
      <mass value="0.7" />
      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
    </inertial>
    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
  </link>
  <link name="left_ankle_pitch_link">
    <inertial>
      <origin xyz="0 0 0" rpy="0 0 0" />
      <mass value="0.12" />
      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
    </inertial>
  </link>
  <link name="left_foot">
    <inertial>
      <origin xyz="0.0225 0 -0.0425" rpy="0 0 0" />
      <mass value="0.6" />
      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
    </inertial>
    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
  </link>
  <link name="left_shoulder_pitch_link">
    <inertial>
      <origin xyz="0 0 -0.012" rpy="0 0 0" />
      <mass value="0.2" />
      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
    </inertial>
    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
  </link>
  <link name="left_shoulder_roll_link">
    <inertial>
      <origin xyz="0 0 -0.006" rpy="0 0 0" />
      <mass value="0.2" />
      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
    </inertial>
    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
  </link>
  <link name="left_upper_arm">
    <inertial>
      <origin xyz="0 0 -0.049" rpy="0 0 0" />
      <mass value="0.33" />
      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
    </inertial>
    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
  </link>
  <link name="left_forearm">
    <inertial>
      <origin xyz="0 0 -0.017" rpy="0 0 0" />
      <mass value="0.22" />
      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
    </inertial>
    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
  </link>
  <link name="left_forearm_roll_link">
    <inertial>
      <origin xyz="0 0 -0.035" rpy="0 0 0" />
      <mass value="0.24" />
      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
    </inertial>
    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
  </link>
  <link name="left_wrist_pitch_link">
    <inertial>
      <origin xyz="0 0 -0.008" rpy="0 0 0" />
      <mass value="0.1" />
      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
    </inertial>
    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
  </link>
  <link name="left_hand">
    <inertial>
      <origin xyz="0 0 -0.021" rpy="0 0 0" />
      <mass value="0.16" />
      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
    </inertial>
    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
  </link>
  <link name="left_index_mcp_link">
    <inertial>
      <origin xyz="0 0 -0.0135" rpy="0 0 0" />
      <mass value="0.009" />
      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
    </inertial>
    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
  </link>
  <link name="left_index_pip_link">
    <inertial>
      <origin xyz="0 0 -0.0095" rpy="0 0 0" />
      <mass value="0.006" />
      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
    </inertial>
    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
  </link>
  <link name="left_index_dip_link">
    <inertial>
      <origin xyz="0 0 -0.007" rpy="0 0 0" />
      <mass value="0.004" />
      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
    </inertial>
    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
  </link>
  <link name="left_middle_mcp_link">
    <inertial>
      <origin xyz="0 0 -0.015" rpy="0 0 0" />
      <mass value="0.009" />
      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
    </inertial>
    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
  </link>
  <link name="left_middle_pip_link">
    <inertial>
      <origin xyz="0 0 -0.0105" rpy="0 0 0" />
      <mass value="0.006" />
      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
    </inertial>
    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
  </link>
  <link name="left_middle_dip_link">
    <inertial>
      <origin xyz="0 0 -0.0075" rpy="0 0 0" />
      <mass value="0.004" />
      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
    </inertial>
    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
  </link>
  <link name="left_ring_mcp_link">
    <inertial>
      <origin xyz="0 0 -0.014" rpy="0 0 0" />
      <mass value="0.009" />
      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
    </inertial>
    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
  </link>
  <link name="left_ring_pip_link">
    <inertial>
      <origin xyz="0 0 -0.01" rpy="0 0 0" />
      <mass value="0.006" />
      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
    </inertial>
    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
  </link>
  <link name="left_ring_dip_link">
    <inertial>
      <origin xyz="0 0 -0.007" rpy="0 0 0" />
      <mass value="0.004" />
      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
    </inertial>
    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
  </link>
  <link name="left_little_mcp_link">
    <inertial>
      <origin xyz="0 0 -0.011" rpy="0 0 0" />
      <mass value="0.009" />
      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
    </inertial>
    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
  </link>
  <link name="left_little_pip_link">
    <inertial>
      <origin xyz="0 0 -0.008" rpy="0 0 0" />
      <mass value="0.006" />
      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
    </inertial>
    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
  </link>
  <link name="left_little_dip_link">
    <inertial>
      <origin xyz="0 0 -0.006" rpy="0 0 0" />
      <mass value="0.004" />
      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
    </inertial>
    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
  </link>
  <link name="left_thumb_cmc_link">
    <inertial>
      <origin xyz="0 0 0" rpy="0 0 0" />
      <mass value="0.009" />
      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
    </inertial>
    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
  </link>
  <link name="left_thumb_spread_link">
    <inertial>
      <origin xyz="0 0 -0.0105" rpy="0 0 0" />
      <mass value="0.01" />
      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
    </inertial>
    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
  </link>
  <link name="left_thumb_mcp_link">
    <inertial>
      <origin xyz="0 0 -0.01" rpy="0 0 0" />
      <mass value="0.008" />
      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
    </inertial>
    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
  </link>
  <link name="left_thumb_ip_link">
    <inertial>
      <origin xyz="0 0 -0.0085" rpy="0 0 0" />
      <mass value="0.005" />
      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
    </inertial>
    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
  </link>
  <link name="right_hip_yaw_link">
    <inertial>
      <origin xyz="0 0 0" rpy="0 0 0" />
      <mass value="0.1" />
      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
    </inertial>
  </link>
  <link name="right_hip_roll_link">
    <inertial>
      <origin xyz="0 0 0" rpy="0 0 0" />
      <mass value="0.15" />
      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
    </inertial>
  </link>
  <link name="right_thigh">
    <inertial>
      <origin xyz="0 0 -0.095" rpy="0 0 0" />
      <mass value="0.95" />
      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
    </inertial>
    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
  </link>
  <link name="right_shin">
    <inertial>
      <origin xyz="0 0 -0.094" rpy="0 0 0" />
      <mass value="0.7" />
      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
    </inertial>
    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
  </link>
  <link name="right_ankle_pitch_link">
    <inertial>
      <origin xyz="0 0 0" rpy="0 0 0" />
      <mass value="0.12" />
      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
    </inertial>
  </link>
  <link name="right_foot">
    <inertial>
      <origin xyz="0.0225 0 -0.0425" rpy="0 0 0" />
      <mass value="0.6" />
      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
    </inertial>
    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
  </link>
  <link name="right_shoulder_pitch_link">
    <inertial>
      <origin xyz="0 0 -0.012" rpy="0 0 0" />
      <mass value="0.2" />
      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
    </inertial>
    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
  </link>
  <link name="right_shoulder_roll_link">
    <inertial>
      <origin xyz="0 0 -0.006" rpy="0 0 0" />
      <mass value="0.2" />
      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
    </inertial>
    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
  </link>
  <link name="right_upper_arm">
    <inertial>
      <origin xyz="0 0 -0.049" rpy="0 0 0" />
      <mass value="0.33" />
      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
    </inertial>
    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
  </link>
  <link name="right_forearm">
    <inertial>
      <origin xyz="0 0 -0.017" rpy="0 0 0" />
      <mass value="0.22" />
      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
    </inertial>
    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
  </link>
  <link name="right_forearm_roll_link">
    <inertial>
      <origin xyz="0 0 -0.035" rpy="0 0 0" />
      <mass value="0.24" />
      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
    </inertial>
    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
  </link>
  <link name="right_wrist_pitch_link">
    <inertial>
      <origin xyz="0 0 -0.008" rpy="0 0 0" />
      <mass value="0.1" />
      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
    </inertial>
    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
  </link>
  <link name="right_hand">
    <inertial>
      <origin xyz="0 0 -0.021" rpy="0 0 0" />
      <mass value="0.16" />
      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
    </inertial>
    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
  </link>
  <link name="right_index_mcp_link">
    <inertial>
      <origin xyz="0 0 -0.0135" rpy="0 0 0" />
      <mass value="0.009" />
      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
    </inertial>
    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
  </link>
  <link name="right_index_pip_link">
    <inertial>
      <origin xyz="0 0 -0.0095" rpy="0 0 0" />
      <mass value="0.006" />
      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
    </inertial>
    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
  </link>
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
